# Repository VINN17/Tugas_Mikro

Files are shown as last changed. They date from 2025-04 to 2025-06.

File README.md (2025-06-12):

# 🚧 Building Automation System (BAS) untuk Pompa Air Jalan Tol
### Solusi Banjir dan Kemacetan saat Hujan Berkepanjangan

<div align="center">
  
</div>

https://github.com/user-attachments/assets/4135e06a-734f-496c-8481-714472587500

## 📚 Daftar Isi

1. [📌 Deskripsi Proyek](#-deskripsi-proyek)
2. [🎯 Tujuan Proyek](#-tujuan-proyek)
3. [🛠️ Teknologi dan Komponen](#️-teknologi-dan-komponen)
4. [⚙️ Cara Kerja Sistem](#️-cara-kerja-sistem)
5. [🧩 Diagram Alur Sistem](#-diagram-alur-sistem)
6. [🌟 Keunggulan Proyek](#-keunggulan-proyek)
7. [📈 Potensi Pengembangan](#-potensi-pengembangan)
8. [🤝 Kolaborasi & Dukungan](#-kolaborasi--dukungan)
9. [👥 Struktur Tim](#-struktur-tim)
10. [📩 Hubungi Kami](#-hubungi-kami)

---

## 📌 Deskripsi Proyek

**Building Automation Systems** ini dirancang untuk mengotomatisasi pengoperasian **pompa air pada jalan tol** guna mengatasi genangan atau banjir secara cepat dan efisien.

Dengan memanfaatkan sensor debit dan volume air, sistem ini mampu menghidupkan atau mematikan pompa secara otomatis berdasarkan data real-time, sehingga meningkatkan **keamanan** dan **kenyamanan** pengguna jalan.

> Dikembangkan berbasis **Arduino Uno** dan sistem monitoring berbasis GUI, proyek ini menawarkan solusi otomasi yang **andal**, **efisien**, dan **mudah diimplementasikan**.

---

## 🎯 Tujuan Proyek

* **Efisiensi Operasional Maksimal**
  Sistem mengeliminasi keterlambatan manual dan mengoptimalkan respons terhadap kondisi air.

* **Minimalkan Risiko Human Error**
  Pengambilan keputusan berbasis data sensor menghindari kesalahan dalam penanganan banjir.

* **Solusi Otomasi Biaya Terjangkau**
  Menggunakan komponen yang tersedia di pasaran dengan biaya rendah, ideal untuk skalabilitas.

---

## 🛠️ Teknologi dan Komponen



| Komponen | Spesifikasi |
| --- | --- |
| Mikrokontroler | Arduino Uno |
| Sensor Debit Air | Pressure Sensor |
| Sensor Volume Air  | Ultrasonic / Water Level Sensor |
| Aktuator | Pompa Air + Relay Module |
| Antarmuka Pengguna | GUI berbasis Figma (Start/Stop, Monitoring)  |
| Komunikasi Data | Serial / Wireless (pengembangan selanjutnya) |

---

## ⚙️ Cara Kerja Sistem

1. Sensor membaca **debit** dan **volume air** secara berkala.
2. Data dikirim ke mikrokontroler dan dibandingkan dengan nilai **set point**.
3. **Logika Kendali Otomatis**:

   * Jika data melebihi ambang → **Pompa ON**
   * Jika data aman → **Pompa OFF**
4. Status sistem ditampilkan pada GUI untuk **monitoring real-time**.
5. Operator dapat melakukan **manual override** dari GUI bila dibutuhkan.

---

## 🧩 Diagram Alur Sistem



**Penjelasan Alur:**

* Sistem dimulai melalui tampilan GUI.

* Pengguna memilih mode: **Auto** atau **Manual**.

  * **Auto**: sensor membaca data → kirim ke GUI → kontrol pompa otomatis.
  * **Manual**: pengguna dapat menyalakan/mematikan pompa secara langsung.

* Sistem akan terus berjalan sampai dihentikan manual oleh operator.

---

## 💻 PCB



Diatas  merupakan desain PCB jadi 

---

## 🌟 Keunggulan Proyek

* ✅ **Respon Real-Time** terhadap potensi banjir.
* ✅ **Kontrol Terpusat & Mudah** dari satu GUI.
* ✅ **Terintegrasi dengan IoT/SCADA** untuk masa depan.
* ✅ **Desain Scalable** & mudah diadaptasi ke area baru.
* ✅ **Ramah Anggaran** untuk implementasi massal.

---

## 📈 Potensi Pengembangan

* 🌐 **Integrasi ke IoT Cloud**: akses global & notifikasi otomatis.
* 🔔 **Peringatan SMS/WhatsApp** saat kondisi kritis.
* 🧠 **Prediksi Banjir Berbasis AI**: analisis historis dengan Machine Learning.
* 🏙️ **Kompatibel dengan Smart City Infrastructure**.

---

## 🤝 Kolaborasi & Dukungan

Kami membuka peluang kerja sama dengan:

* 🔧 **Investor teknologi** yang tertarik pada otomasi infrastruktur.
* 🛣️ **Pemerintah / Operator Jalan Tol** untuk penerapan langsung.
* 🧪 **Startup atau perusahaan R\&D** yang ingin mengembangkan solusi pintar dan berdampak.

> 🎯 Kami siap melakukan presentasi, demo proyek, dan diskusi lanjutan bersama mitra strategis.

---

## 👥 Struktur Tim



| NRP | Nama | Peran Utama |
| --- | --- | --- |
| 2123600010 | Imam | Project Manager |
| 2123600014 | Ferri | Desain PCB |
| 2123600004 | Robith  | Spesialis Hardware |
| 2123600030 | Zach | Pengembang Software |
| 2123600023 | Choirul | Desainer 3D |
| 2123600019 | Andira  | Non-Teknis & Dokumentasi |

---

## 📩 Hubungi Kami

📧 Untuk kerja sama, pertanyaan, atau demo proyek:

**Email Project Manager**: [immarfn17@gmail.com](mailto:immarfn17@gmail.com)

https://github.com/user-attachments/assets/88c9bd39-f75d-4216-a4de-ee6d6c01959d
> 🚀 Mari bersama kita ciptakan masa depan infrastruktur jalan tol yang lebih **cerdas**, **aman**, dan **berkelanjutan**.

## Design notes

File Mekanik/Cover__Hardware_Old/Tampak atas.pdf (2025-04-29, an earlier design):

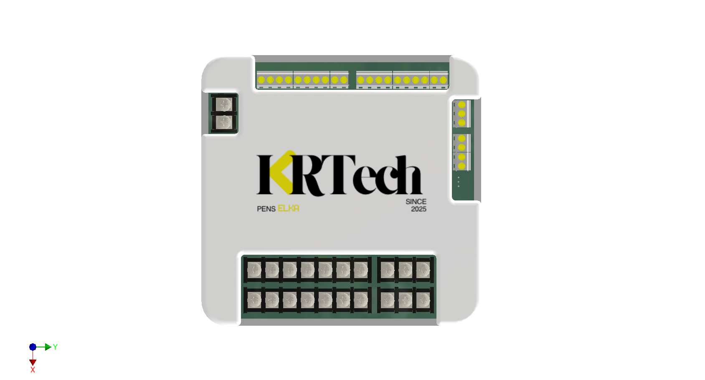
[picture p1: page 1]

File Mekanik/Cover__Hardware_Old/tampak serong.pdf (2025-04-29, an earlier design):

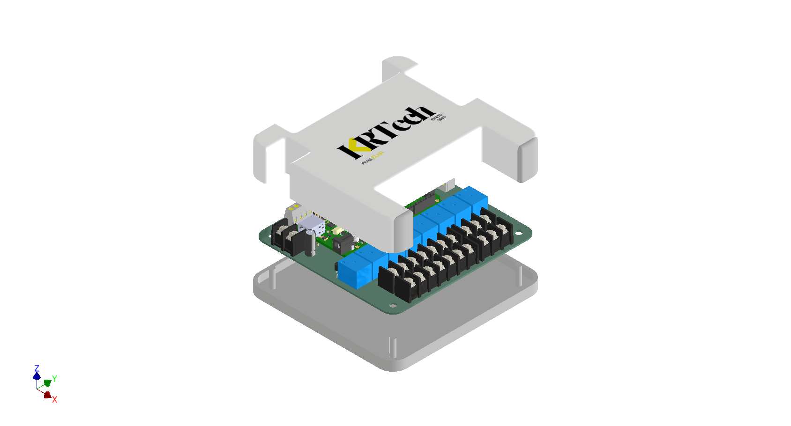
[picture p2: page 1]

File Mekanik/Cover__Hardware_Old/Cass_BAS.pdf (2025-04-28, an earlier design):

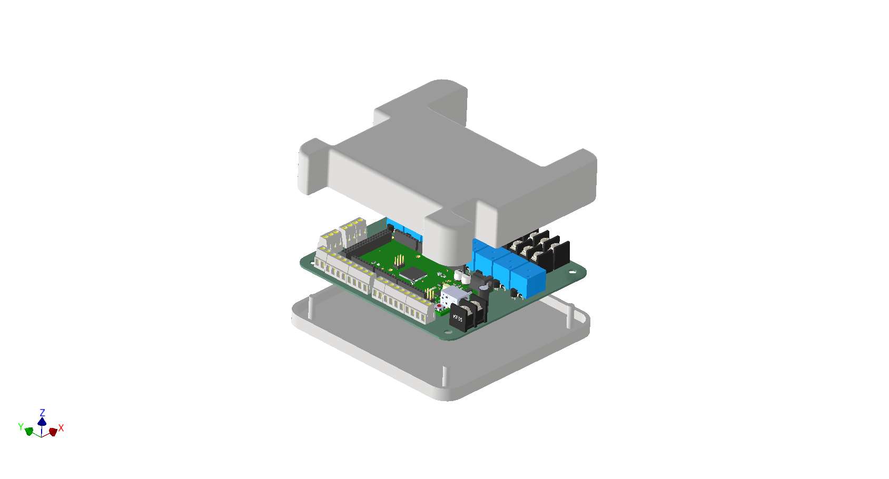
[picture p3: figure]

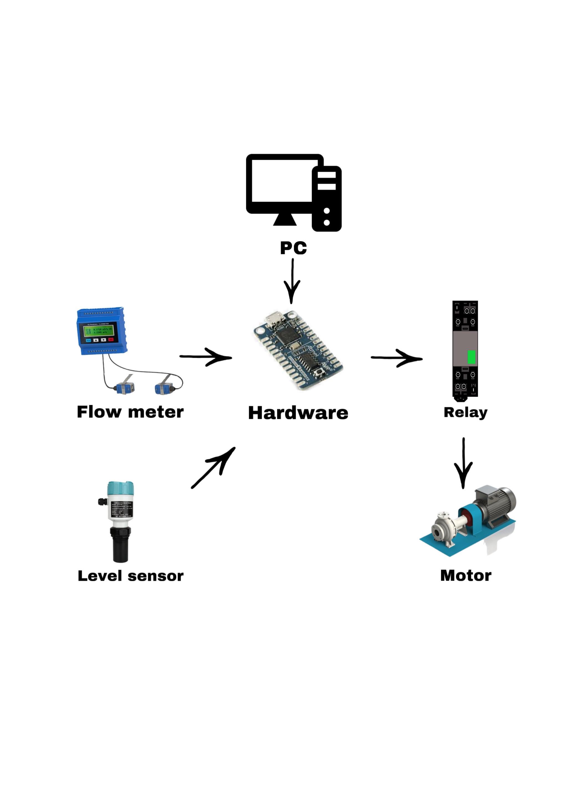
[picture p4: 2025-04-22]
Arsitekture Design.jpeg

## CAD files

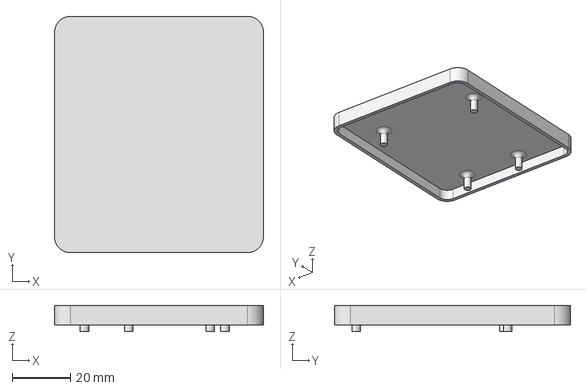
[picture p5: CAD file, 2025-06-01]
Mekanik/Cover_Hardware_New/part1.stp
71.8 x 81.2 x 9.00 mm

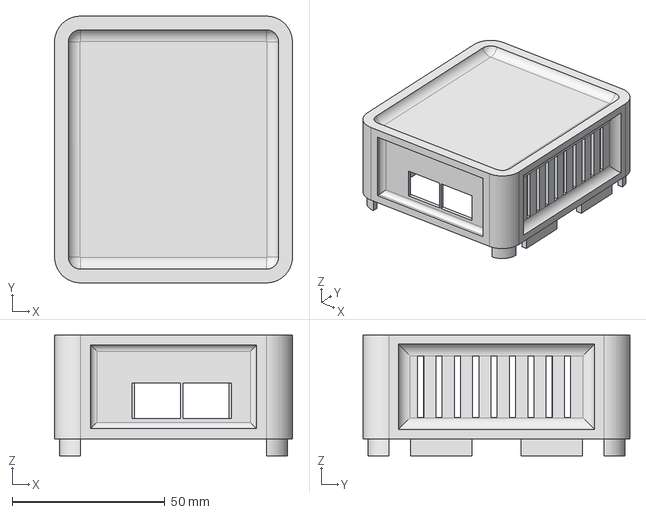
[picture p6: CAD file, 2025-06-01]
Mekanik/Cover_Hardware_New/pirnt3d/Part3.stp
77.8 x 87.2 x 39.5 mm

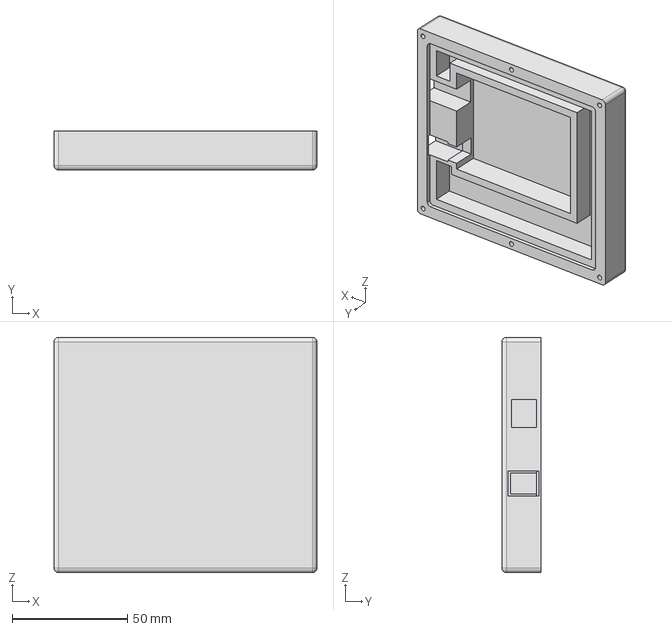
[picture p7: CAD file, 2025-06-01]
Mekanik/Cover_Hardware_New/pirnt3d/12.stp
114.0 x 17.0 x 102.0 mm

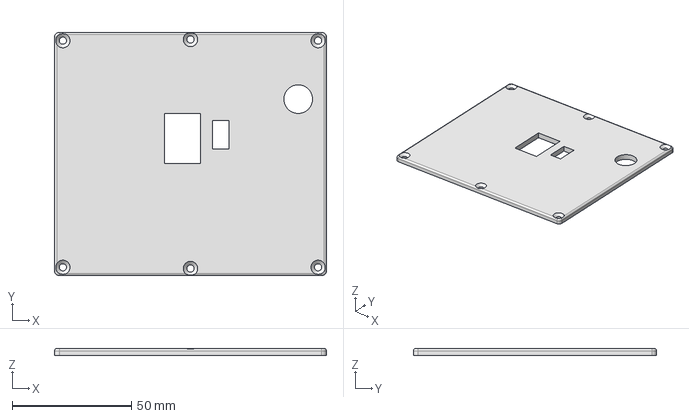
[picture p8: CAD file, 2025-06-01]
Mekanik/Cover_Hardware_New/pirnt3d/tutup cover12.stp
114.0 x 102.0 x 3.00 mm

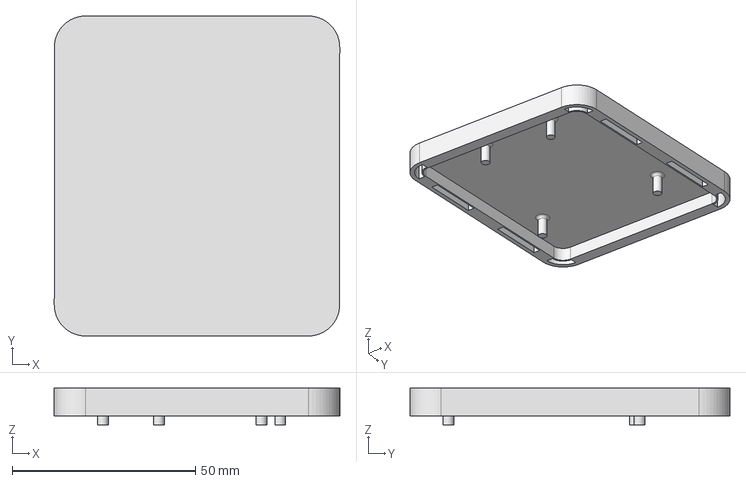
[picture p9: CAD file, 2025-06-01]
Mekanik/Cover_Hardware_New/pirnt3d/part1.stp
77.8 x 87.2 x 10.0 mm

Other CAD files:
Hardware/BAS_Hardware/BAS_Hardware/BAS_Hardware/05KJ_Mini_PCB_Regulator.ipt
Hardware/BAS_Hardware/BAS_Hardware/BAS_Hardware/05KJ_Mini_PCB_Regulator_With_Pin_Assem_.iam
Hardware/BAS_Hardware/BAS_Hardware/BAS_Hardware/1_Male_Pin_2.54_mm.ipt
Hardware/BAS_Hardware/BAS_Hardware/BAS_Hardware/2er Terminal Block.iam
Hardware/BAS_Hardware/BAS_Hardware/BAS_Hardware/3er Terminal Block.iam
Hardware/BAS_Hardware/BAS_Hardware/BAS_Hardware/4er Terminal Block.iam
Hardware/BAS_Hardware/BAS_Hardware/BAS_Hardware/BAS_Hardware 1.12.1.ipt
Hardware/BAS_Hardware/BAS_Hardware/BAS_Hardware/BAS_Hardware 1.40.1.ipt
Hardware/BAS_Hardware/BAS_Hardware/BAS_Hardware/BAS_Hardware 1.7.1.ipt
Hardware/BAS_Hardware/BAS_Hardware/BAS_Hardware/BAS_Hardware_PCB.ipt
Hardware/BAS_Hardware/BAS_Hardware/BAS_Hardware/COMPOUND.ipt
Hardware/BAS_Hardware/BAS_Hardware/BAS_Hardware/D_DO-41_SOD81_P10.16mm_Horizontal.ipt
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

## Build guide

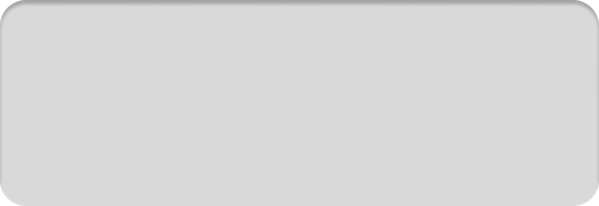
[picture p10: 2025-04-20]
program/Program_Mikro/build/assets/frame0/entry_3.png

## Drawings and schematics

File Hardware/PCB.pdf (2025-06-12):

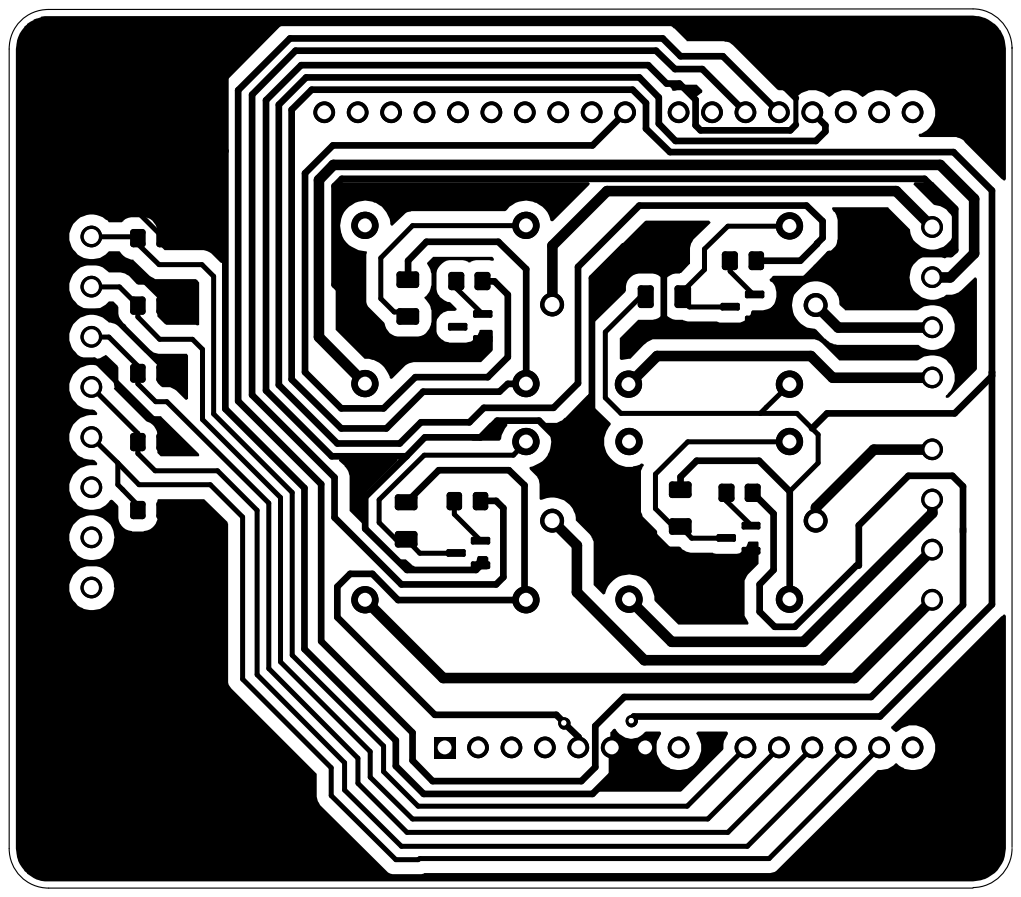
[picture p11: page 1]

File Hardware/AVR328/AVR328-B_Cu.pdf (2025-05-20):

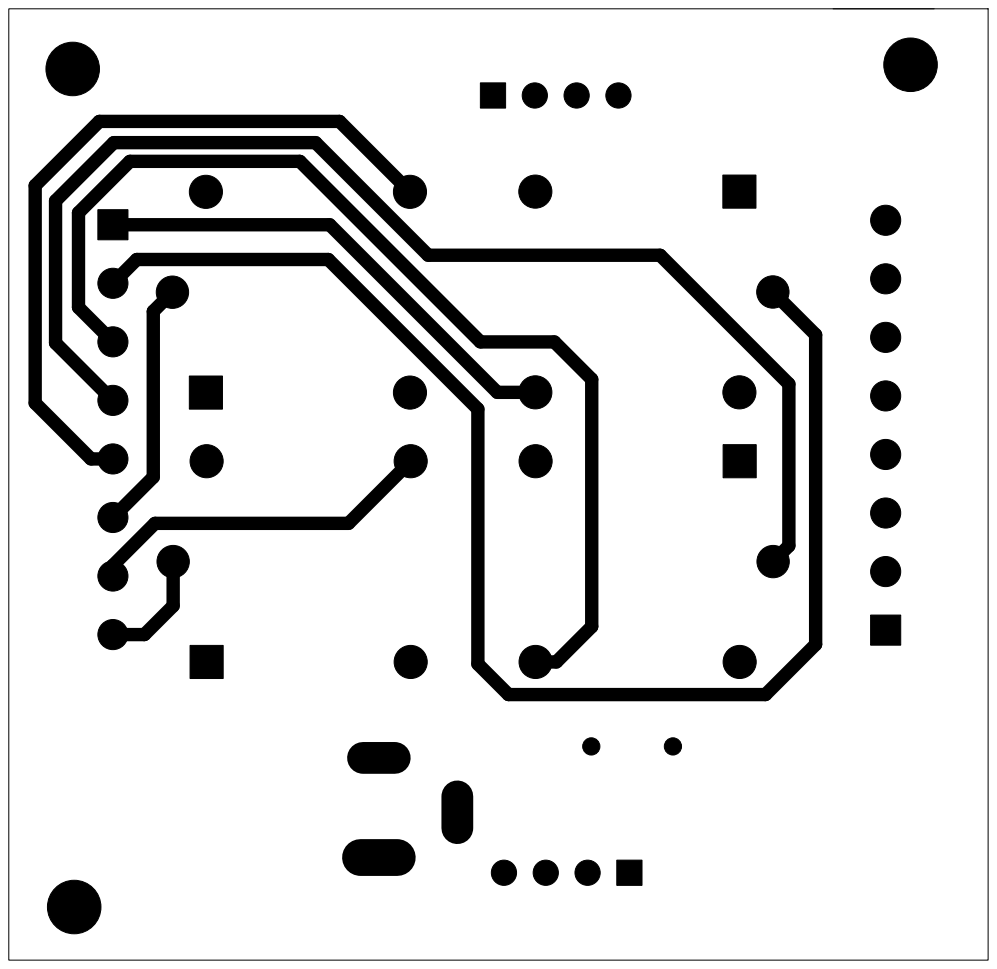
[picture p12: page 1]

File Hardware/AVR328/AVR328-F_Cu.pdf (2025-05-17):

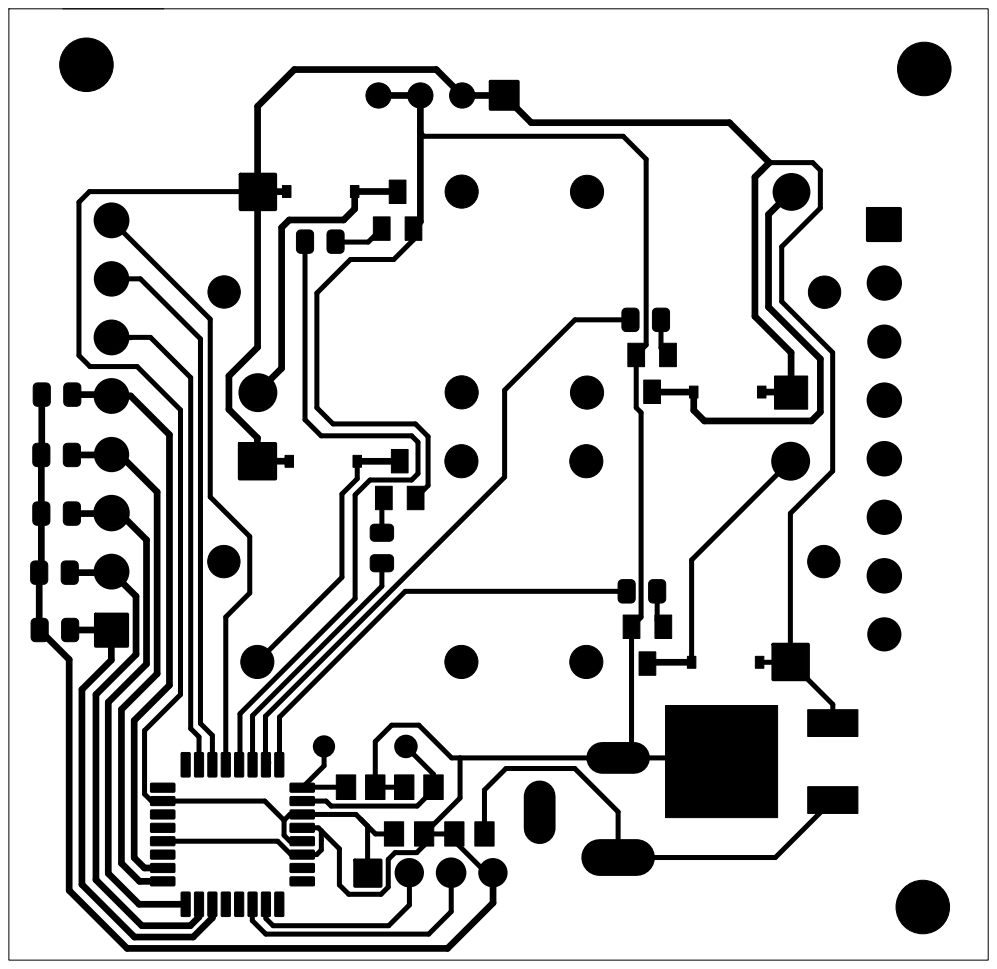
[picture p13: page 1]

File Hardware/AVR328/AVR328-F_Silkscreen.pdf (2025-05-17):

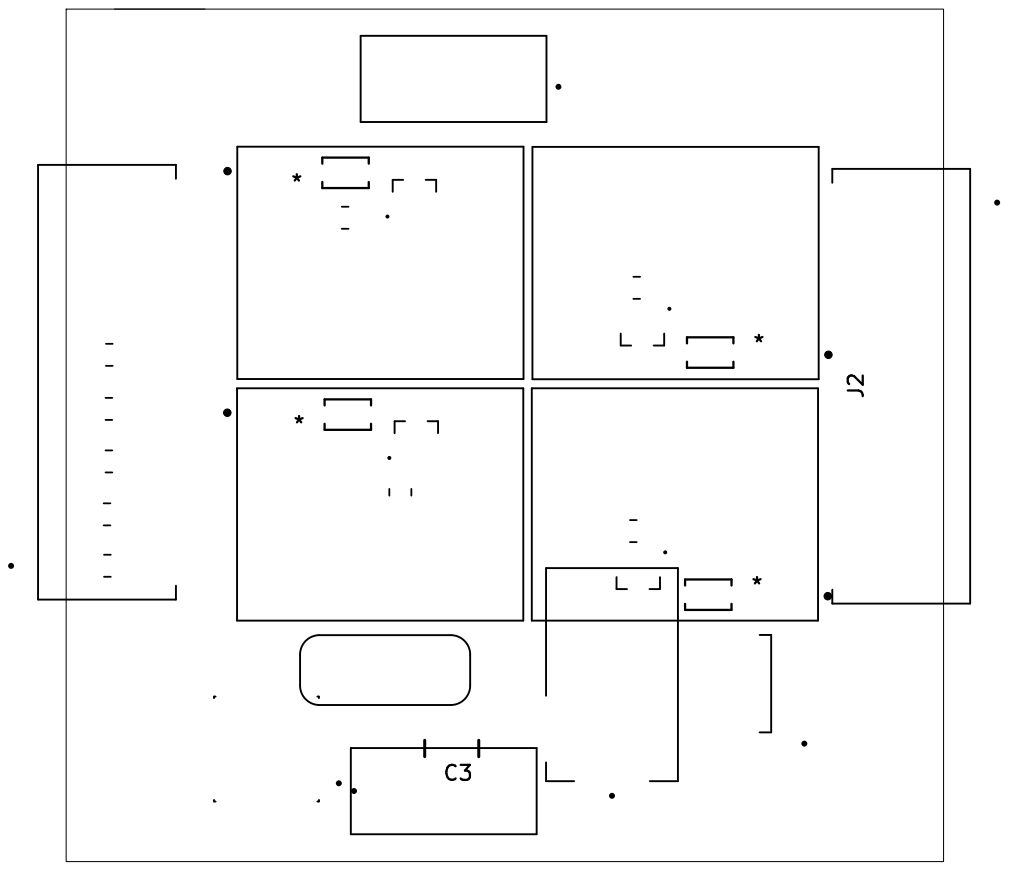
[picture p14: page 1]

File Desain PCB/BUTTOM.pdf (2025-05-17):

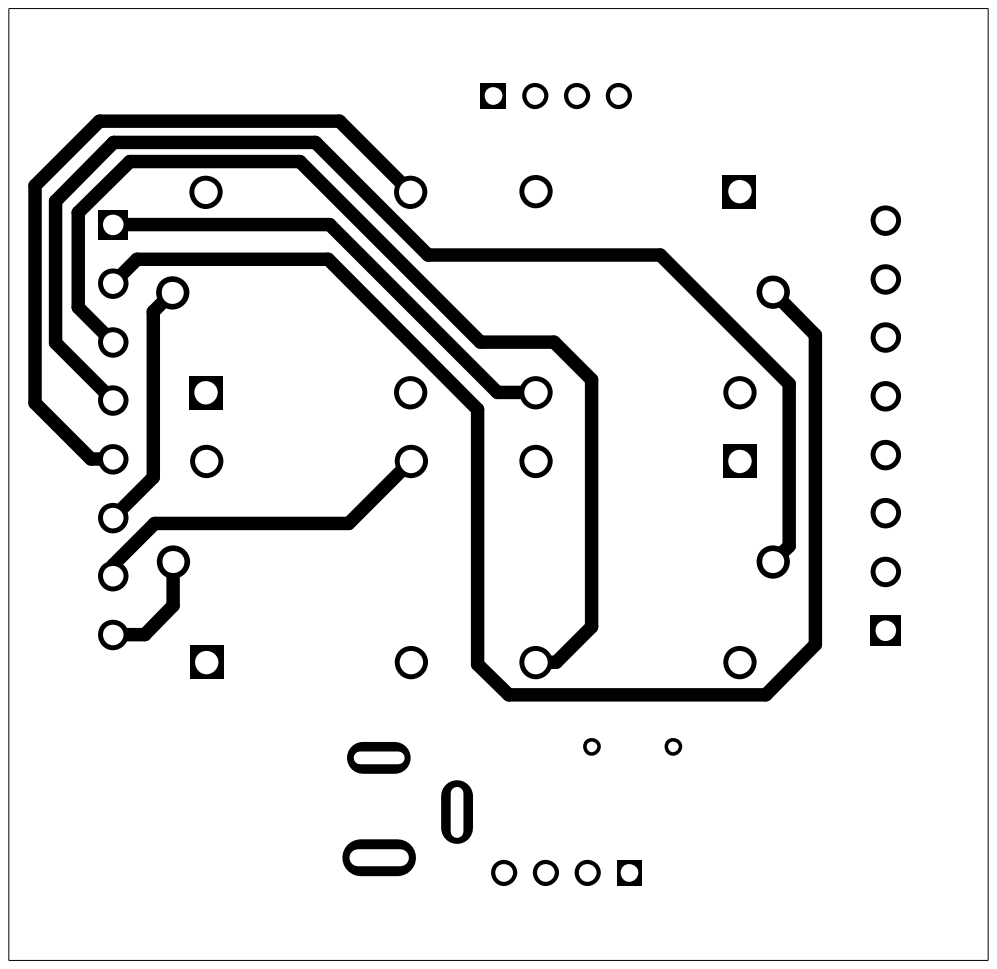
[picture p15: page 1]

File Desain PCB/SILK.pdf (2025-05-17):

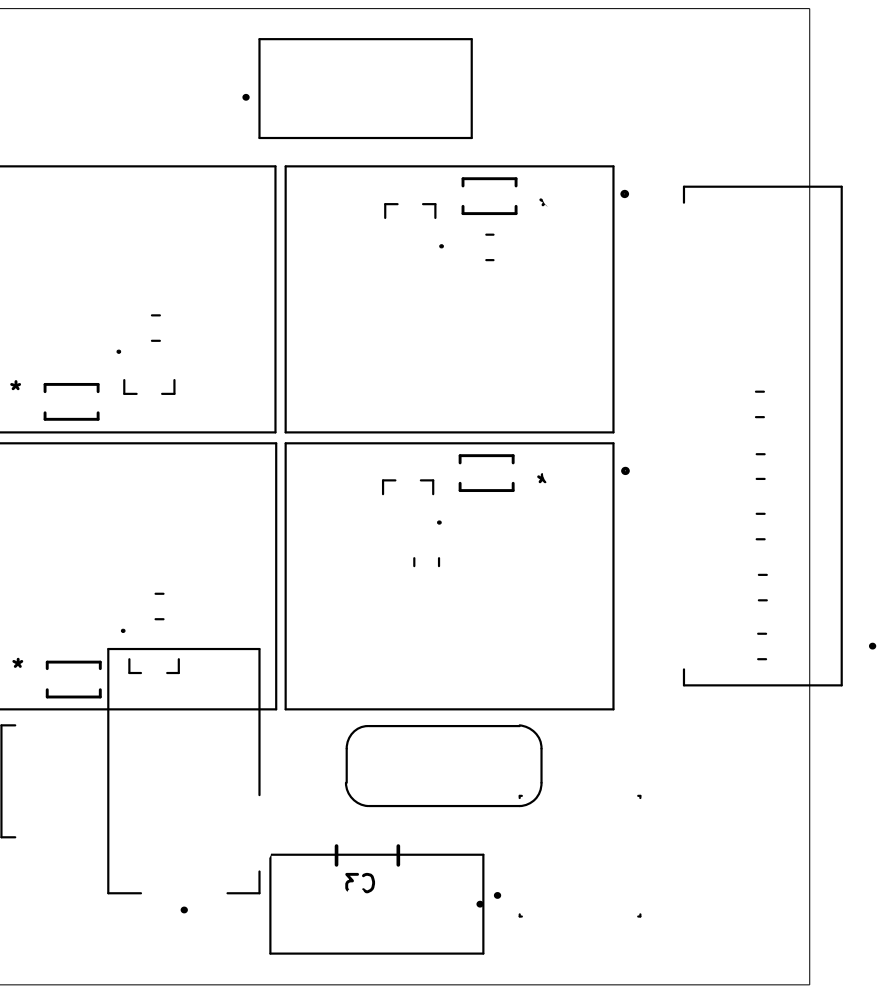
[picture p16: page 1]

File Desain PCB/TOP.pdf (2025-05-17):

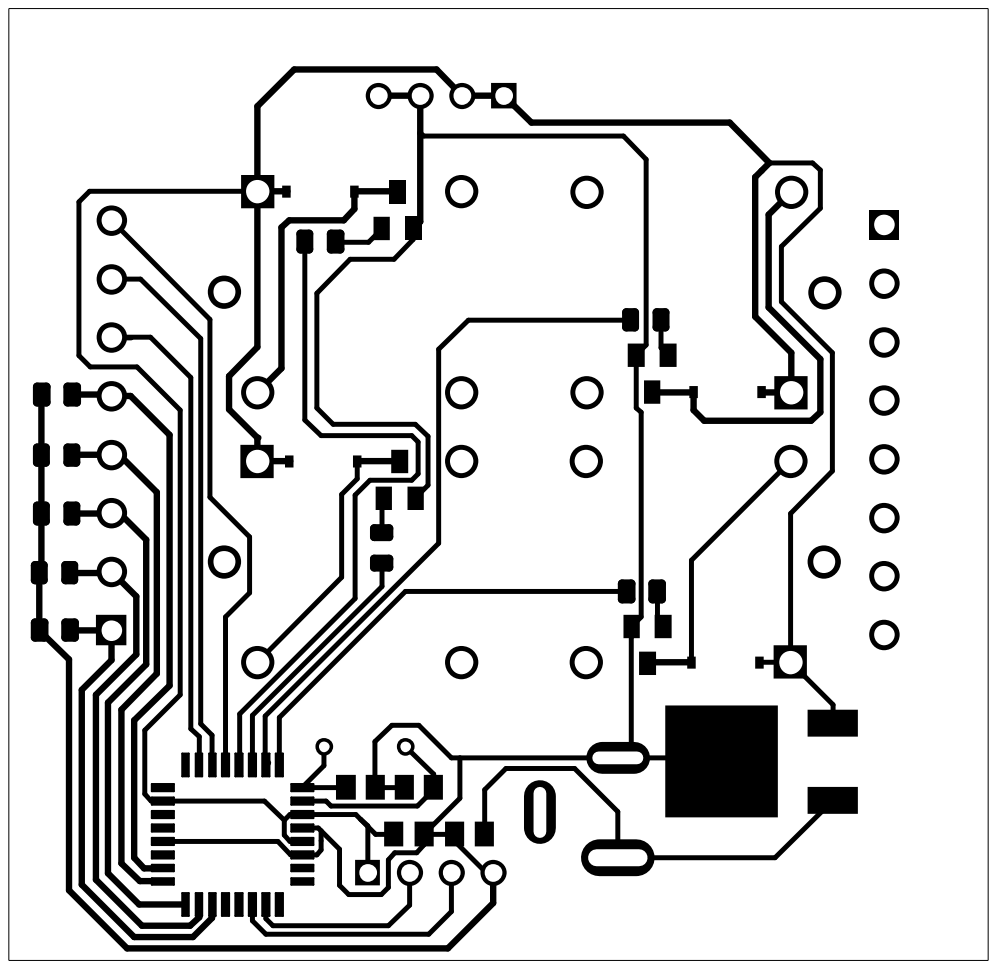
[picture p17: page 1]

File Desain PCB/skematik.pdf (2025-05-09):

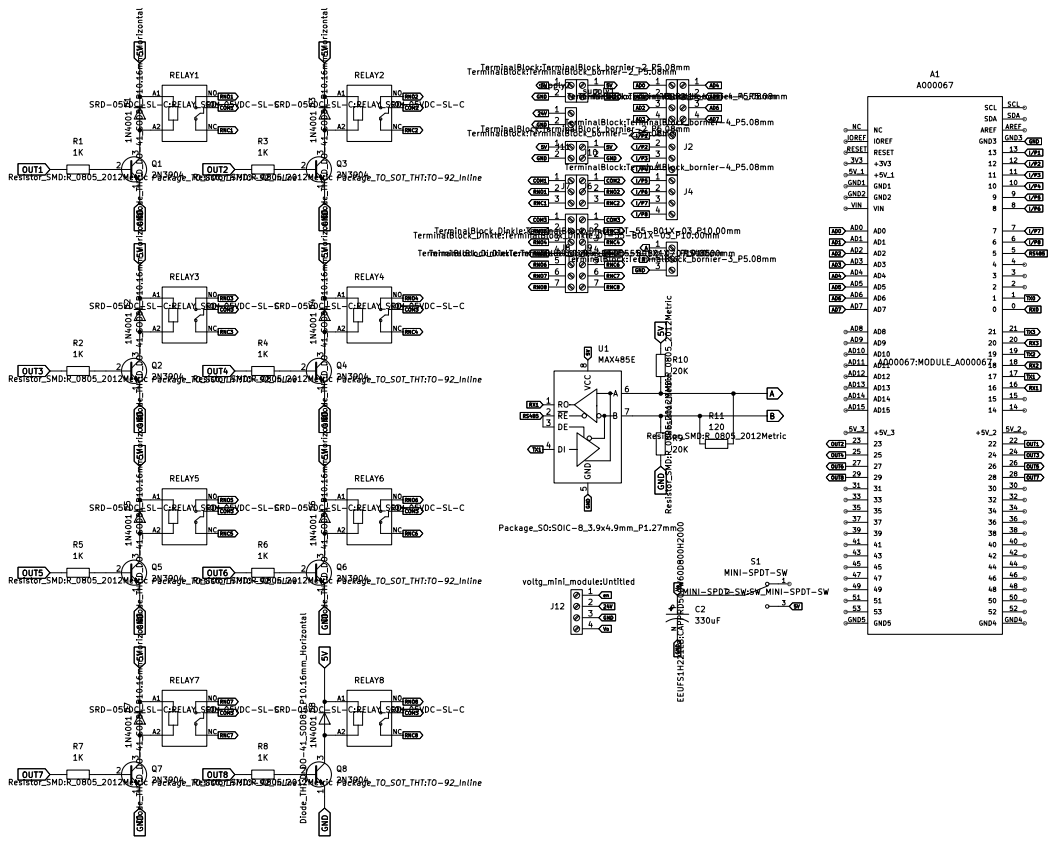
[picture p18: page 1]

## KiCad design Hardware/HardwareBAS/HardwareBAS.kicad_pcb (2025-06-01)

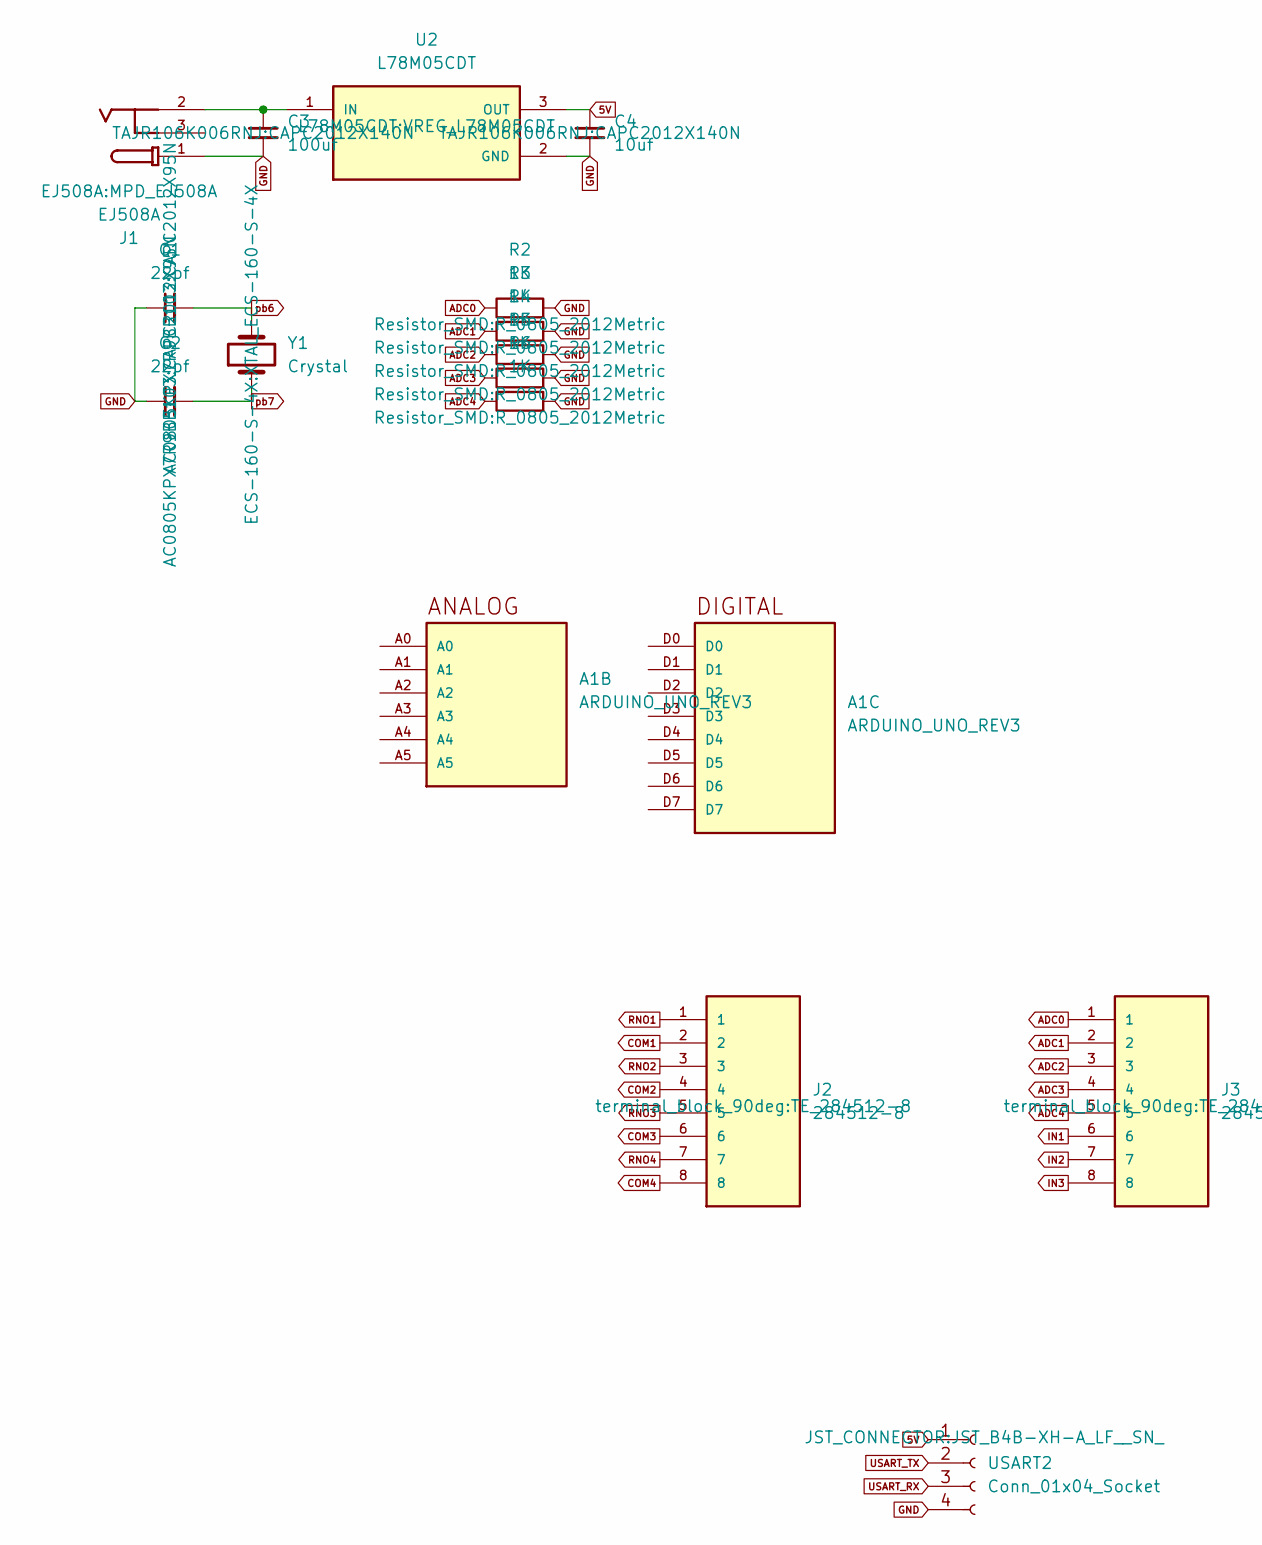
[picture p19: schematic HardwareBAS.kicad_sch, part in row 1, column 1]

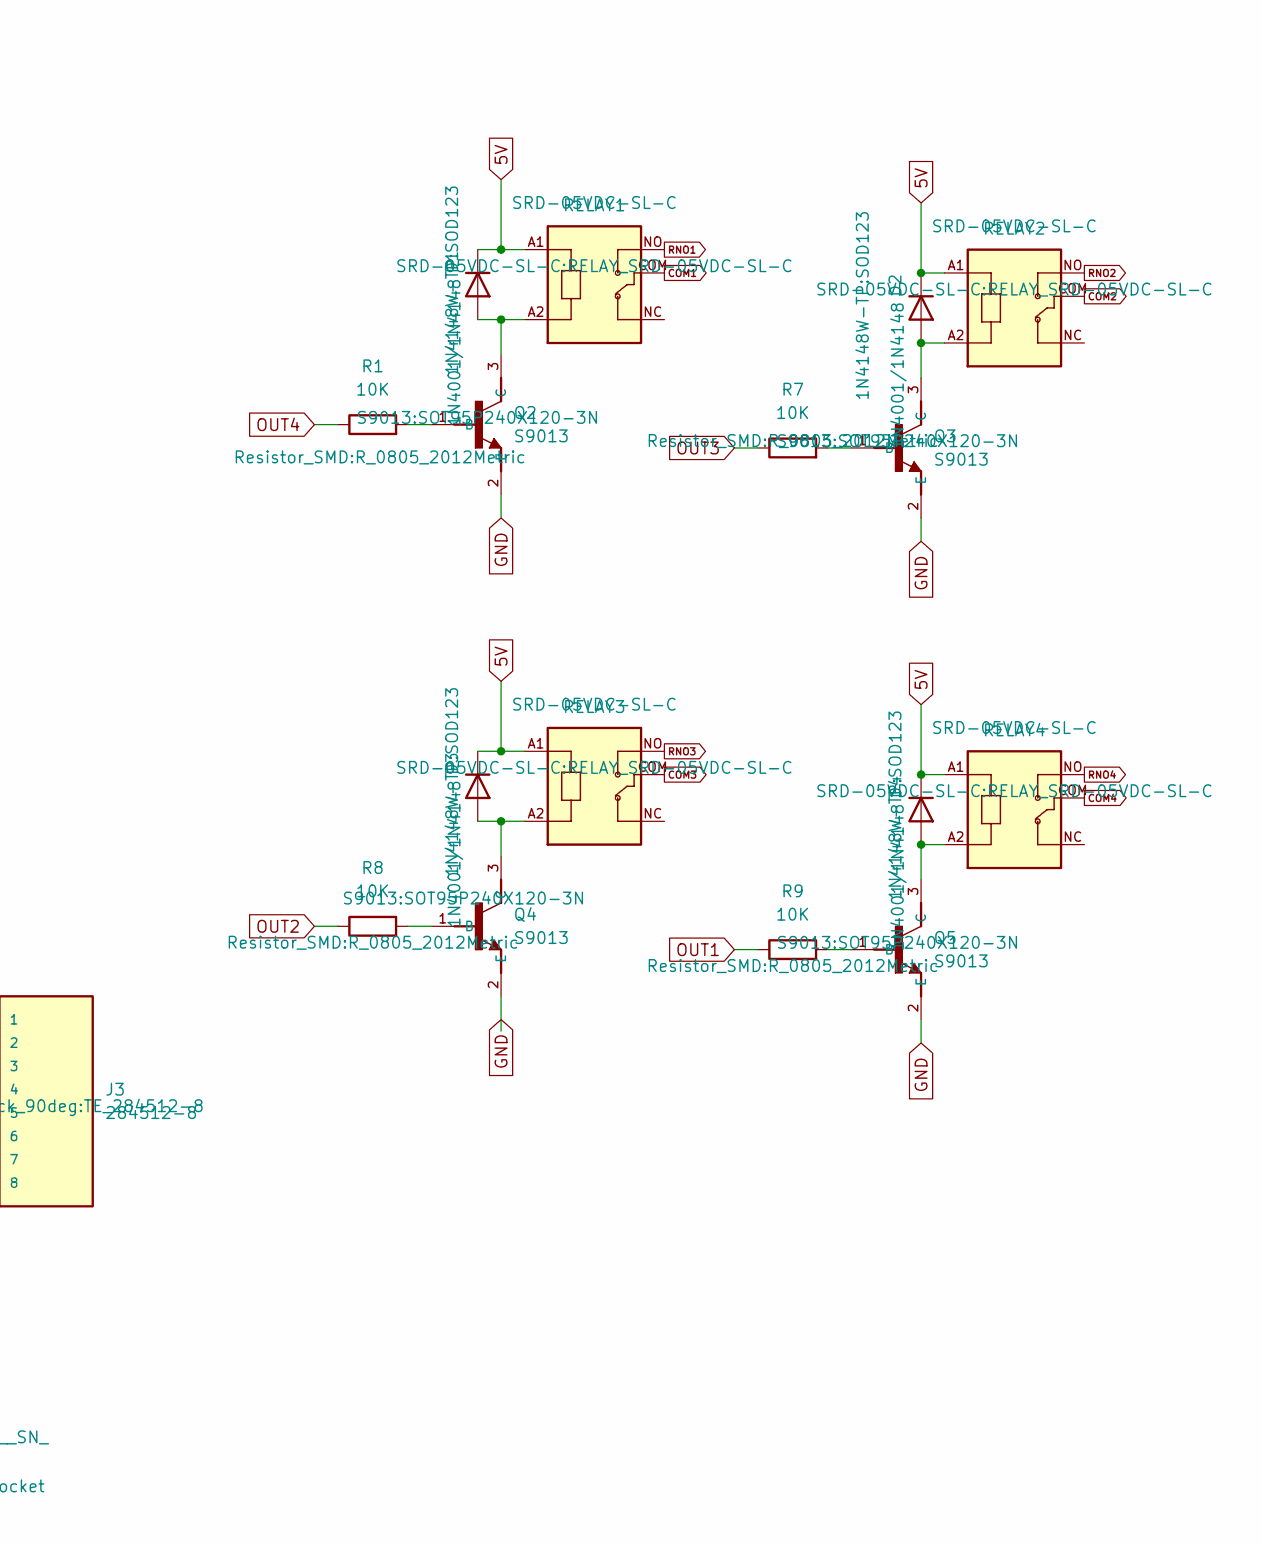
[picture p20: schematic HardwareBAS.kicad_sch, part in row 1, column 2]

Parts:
A1: ARDUINO_UNO_REV3; ARDUINO_ARDUINO_UNO_REV3; PARTREV N/A
C1, C2: 22pf; CAPC2012X95N
C3: 100uf; CAPC2012X140N
C4: 10uf; CAPC2012X140N
D1, D2, D3, D4: 1N4001/1N4148; SOD123
J1: EJ508A; MPD_EJ508A; PARTREV J
J2, J3: 284512-8; TE_284512-8; PARTREV R
Q2, Q3, Q4, Q5: S9013; SOT95P240X120-3N
R1, R7, R8, R9: 10K; R_0805_2012Metric
R2, R3, R4, R5, R6: 1K; R_0805_2012Metric
RELAY1, RELAY2, RELAY3, RELAY4: SRD-05VDC-SL-C; RELAY_SRD-05VDC-SL-C
U2: L78M05CDT; VREG_L78M05CDT; PARTREV 24
USART2: Conn_01x04_Socket; JST_B4B-XH-A_LF__SN_
Y1: Crystal; XTAL_ECS-160-S-4X

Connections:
5V: C4.1, D1.1 (K), D2.1 (K), D3.1 (K), D4.1 (K), RELAY1.A1, RELAY2.A1, RELAY3.A1, RELAY4.A1, U2.3 (OUT), USART2.1
ADC0: J3.1, R2.1
ADC1: J3.2, R3.1
ADC2: J3.3, R4.1
ADC3: J3.4, R5.1
ADC4: J3.5, R6.1
COM1: J2.2, RELAY1.COM
COM2: J2.4, RELAY2.COM
COM3: J2.6, RELAY3.COM
COM4: J2.8, RELAY4.COM
GND: C1.1, C2.1, C3.2, C4.2, J1.1, Q2.2 (E), Q3.2 (E), Q4.2 (E), Q5.2 (E), R2.2, R3.2, R4.2, R5.2, R6.2, U2.2 (GND), USART2.4
IN1: J3.6
IN2: J3.7
IN3: J3.8
unnamed: D1.2 (A), Q2.3 (C), RELAY1.A2
unnamed: D2.2 (A), Q3.3 (C), RELAY2.A2
unnamed: D3.2 (A), Q4.3 (C), RELAY3.A2
unnamed: D4.2 (A), Q5.3 (C), RELAY4.A2
unnamed: Q2.1 (B), R1.2
unnamed: Q3.1 (B), R7.2
unnamed: Q4.1 (B), R8.2
unnamed: Q5.1 (B), R9.2
unnamed: C3.1, J1.2, U2.1 (IN)
OUT1: R9.1
OUT2: R8.1
OUT3: R7.1
OUT4: R1.1
RNO1: J2.1, RELAY1.NO
RNO2: J2.3, RELAY2.NO
RNO3: J2.5, RELAY3.NO
RNO4: J2.7, RELAY4.NO
USART_RX: USART2.3
USART_TX: USART2.2
pb6: C1.2, Y1.2
pb7: C2.2, Y1.1

Board: 2 copper layers, 32 parts (0 on the bottom side), 26 nets, no tracks yet.

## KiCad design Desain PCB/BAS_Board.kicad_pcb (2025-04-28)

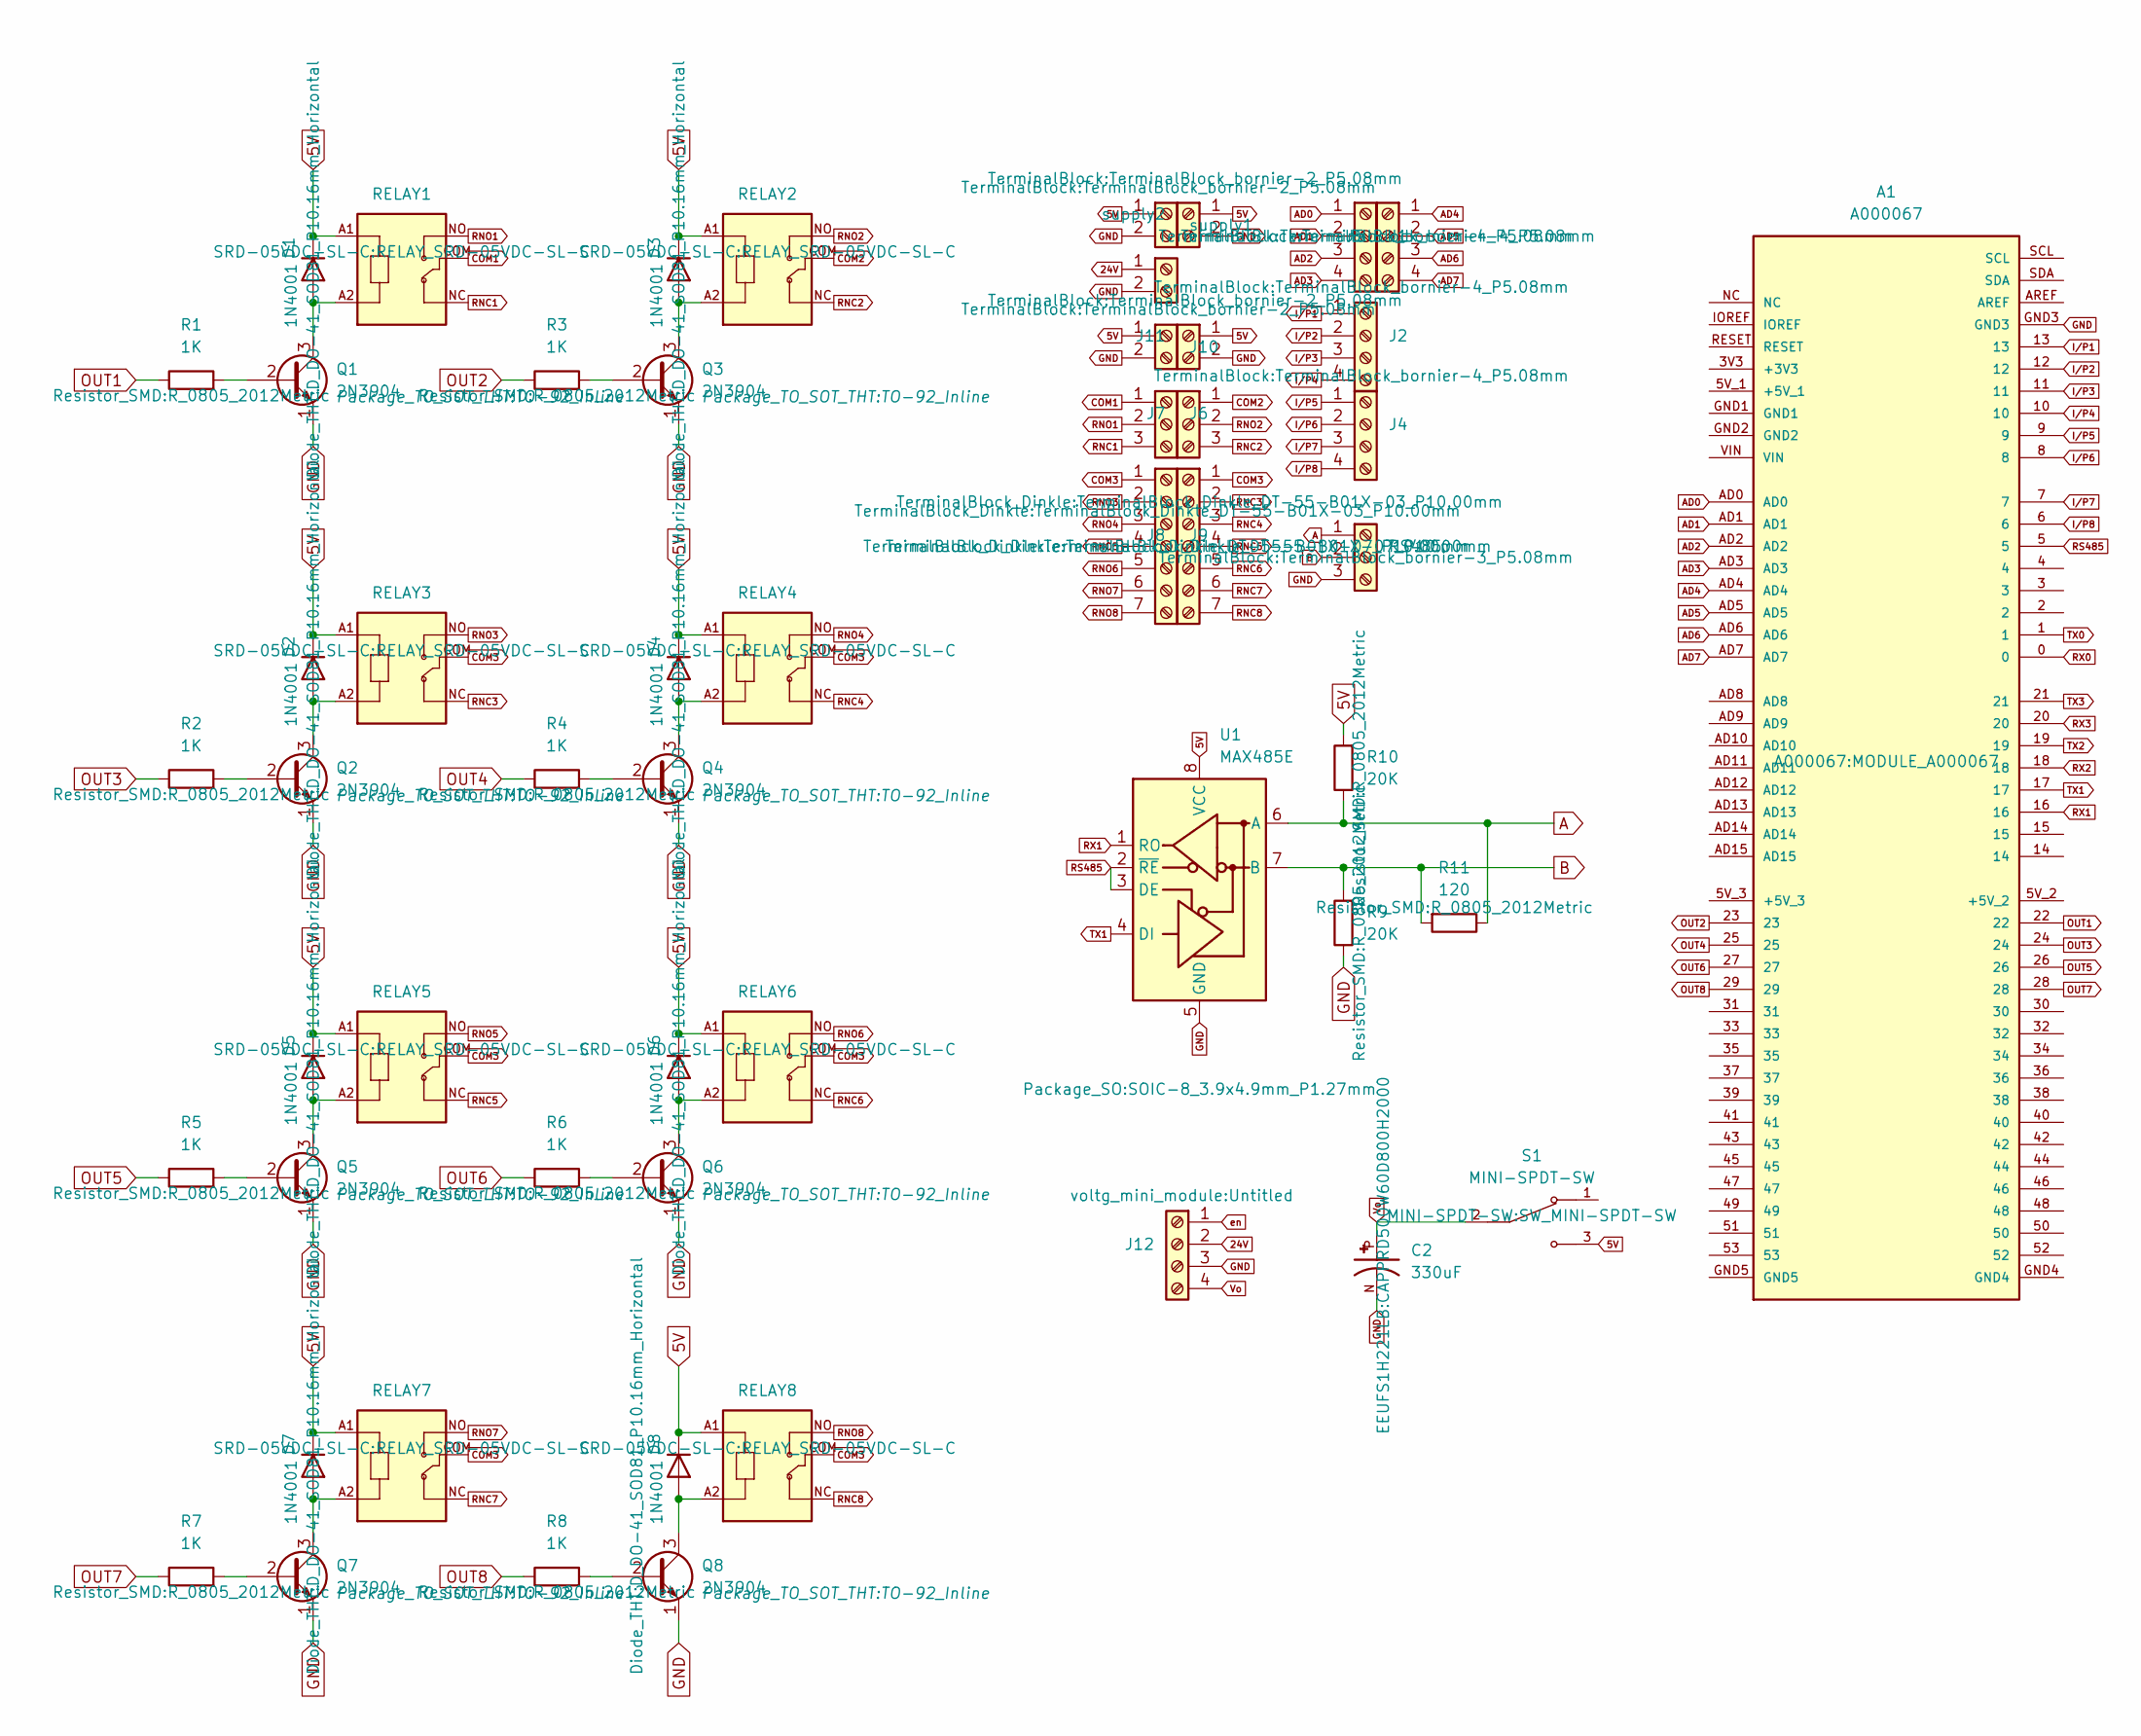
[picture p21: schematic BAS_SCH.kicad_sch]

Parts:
A1: A000067; MODULE_A000067; PARTREV 3; DigiKey_Part_Number 1050-1018-ND
C2: 330uF; CAPPRD500W60D800H2000; PARTREV 28-FEB-20; DigiKey_Part_Number P122329CT-ND
D1, D2, D3, D4, D5, D6, D7, D8: 1N4001; D_DO-41_SOD81_P10.16mm_Horizontal
J1, J2, J4, J5: Screw_Terminal_01x04; TerminalBlock_bornier-4_P5.08mm
J6, J7: Screw_Terminal_01x03; TerminalBlock_Dinkle_DT-55-B01X-03_P10.00mm
J8, J9: Screw_Terminal_01x07; TerminalBlock_Dinkle_DT-55-B01X-07_P10.00mm
J10, J11: Screw_Terminal_01x02; TerminalBlock_bornier-2_P5.08mm
J12: Screw_Terminal_01x04; Untitled
Power1: Screw_Terminal_01x02; TerminalBlock_Dinkle_DT-55-B01X-02_P10.00mm
Q1, Q2, Q3, Q4, Q5, Q6, Q7, Q8: 2N3904; TO-92_Inline
R1, R2, R3, R4, R5, R6, R7, R8: 1K; R_0805_2012Metric
R9, R10: 20K; R_0805_2012Metric
R11: 120; R_0805_2012Metric
RELAY1, RELAY2, RELAY3, RELAY4, RELAY5, RELAY6, RELAY7, RELAY8: SRD-05VDC-SL-C; RELAY_SRD-05VDC-SL-C
RS485: Screw_Terminal_01x03; TerminalBlock_bornier-3_P5.08mm
S1: MINI-SPDT-SW; SW_MINI-SPDT-SW; PARTREV C
U1: MAX485E; SOIC-8_3.9x4.9mm_P1.27mm
supply1, supply2: Screw_Terminal_01x02; TerminalBlock_bornier-2_P5.08mm

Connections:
5V: D1.1 (K), D2.1 (K), D3.1 (K), D4.1 (K), D5.1 (K), D6.1 (K), D7.1 (K), D8.1 (K), J10.1, J11.1, R10.2, RELAY1.A1, RELAY2.A1, RELAY3.A1, RELAY4.A1, RELAY5.A1, RELAY6.A1, RELAY7.A1, RELAY8.A1, S1.3, U1.8 (VCC), supply1.1, supply2.1
24V: J12.2, Power1.1
A: R10.1, R11.1, RS485.1, U1.6 (A)
AD0: A1.AD0, J1.1
AD1: A1.AD1, J1.2
AD2: A1.AD2, J1.3
AD3: A1.AD3, J1.4
AD4: A1.AD4, J5.1
AD5: A1.AD5, J5.2
AD6: A1.AD6, J5.3
AD7: A1.AD7, J5.4
B: R9.2, R11.2, RS485.2, U1.7 (B)
COM1: J6.1, RELAY1.COM
COM2: J7.1, RELAY2.COM
COM3: J8.1, J9.1, RELAY3.COM, RELAY4.COM, RELAY5.COM, RELAY6.COM, RELAY7.COM, RELAY8.COM
GND: A1.GND3, C2.N, J10.2, J11.2, J12.3, Power1.2, Q1.1 (E), Q2.1 (E), Q3.1 (E), Q4.1 (E), Q5.1 (E), Q6.1 (E), Q7.1 (E), Q8.1 (E), R9.1, RS485.3, U1.5 (GND), supply1.2, supply2.2
I/P1: A1.13, J2.1
I/P2: A1.12, J2.2
I/P3: A1.11, J2.3
I/P4: A1.10, J2.4
I/P5: A1.9, J4.1
I/P6: A1.8, J4.2
I/P7: A1.7, J4.3
I/P8: A1.6, J4.4
unnamed: D1.2 (A), Q1.3 (C), RELAY1.A2
unnamed: D2.2 (A), Q2.3 (C), RELAY3.A2
unnamed: D3.2 (A), Q3.3 (C), RELAY2.A2
unnamed: D4.2 (A), Q4.3 (C), RELAY4.A2
unnamed: D5.2 (A), Q5.3 (C), RELAY5.A2
unnamed: D6.2 (A), Q6.3 (C), RELAY6.A2
unnamed: D7.2 (A), Q7.3 (C), RELAY7.A2
unnamed: D8.2 (A), Q8.3 (C), RELAY8.A2
unnamed: Q1.2 (B), R1.2
unnamed: Q2.2 (B), R2.2
unnamed: Q3.2 (B), R3.2
unnamed: Q4.2 (B), R4.2
unnamed: Q5.2 (B), R5.2
unnamed: Q6.2 (B), R6.2
unnamed: Q7.2 (B), R7.2
unnamed: Q8.2 (B), R8.2
OUT1: A1.22, R1.1
OUT2: A1.23, R3.1
OUT3: A1.24, R2.1
OUT4: A1.25, R4.1
OUT5: A1.26, R5.1
OUT6: A1.27, R6.1
OUT7: A1.28, R7.1
OUT8: A1.29, R8.1
RNC1: J6.3, RELAY1.NC
RNC2: J7.3, RELAY2.NC
RNC3: J8.2, RELAY3.NC
RNC4: J8.3, RELAY4.NC
RNC5: J8.4, RELAY5.NC
RNC6: J8.5, RELAY6.NC
RNC7: J8.6, RELAY7.NC
RNC8: J8.7, RELAY8.NC
RNO1: J6.2, RELAY1.NO
RNO2: J7.2, RELAY2.NO
RNO3: J9.2, RELAY3.NO
RNO4: J9.3, RELAY4.NO
RNO5: J9.4, RELAY5.NO
RNO6: J9.5, RELAY6.NO
RNO7: J9.6, RELAY7.NO
RNO8: J9.7, RELAY8.NO
RS485: A1.5, U1.2 (~RE), U1.3 (DE)
RX0: A1.0
RX1: A1.16, U1.1 (RO)
RX2: A1.18
RX3: A1.20
TX0: A1.1
TX1: A1.17, U1.4 (DI)
TX2: A1.19
TX3: A1.21
Vo: C2.P, J12.4, S1.2
en: J12.1

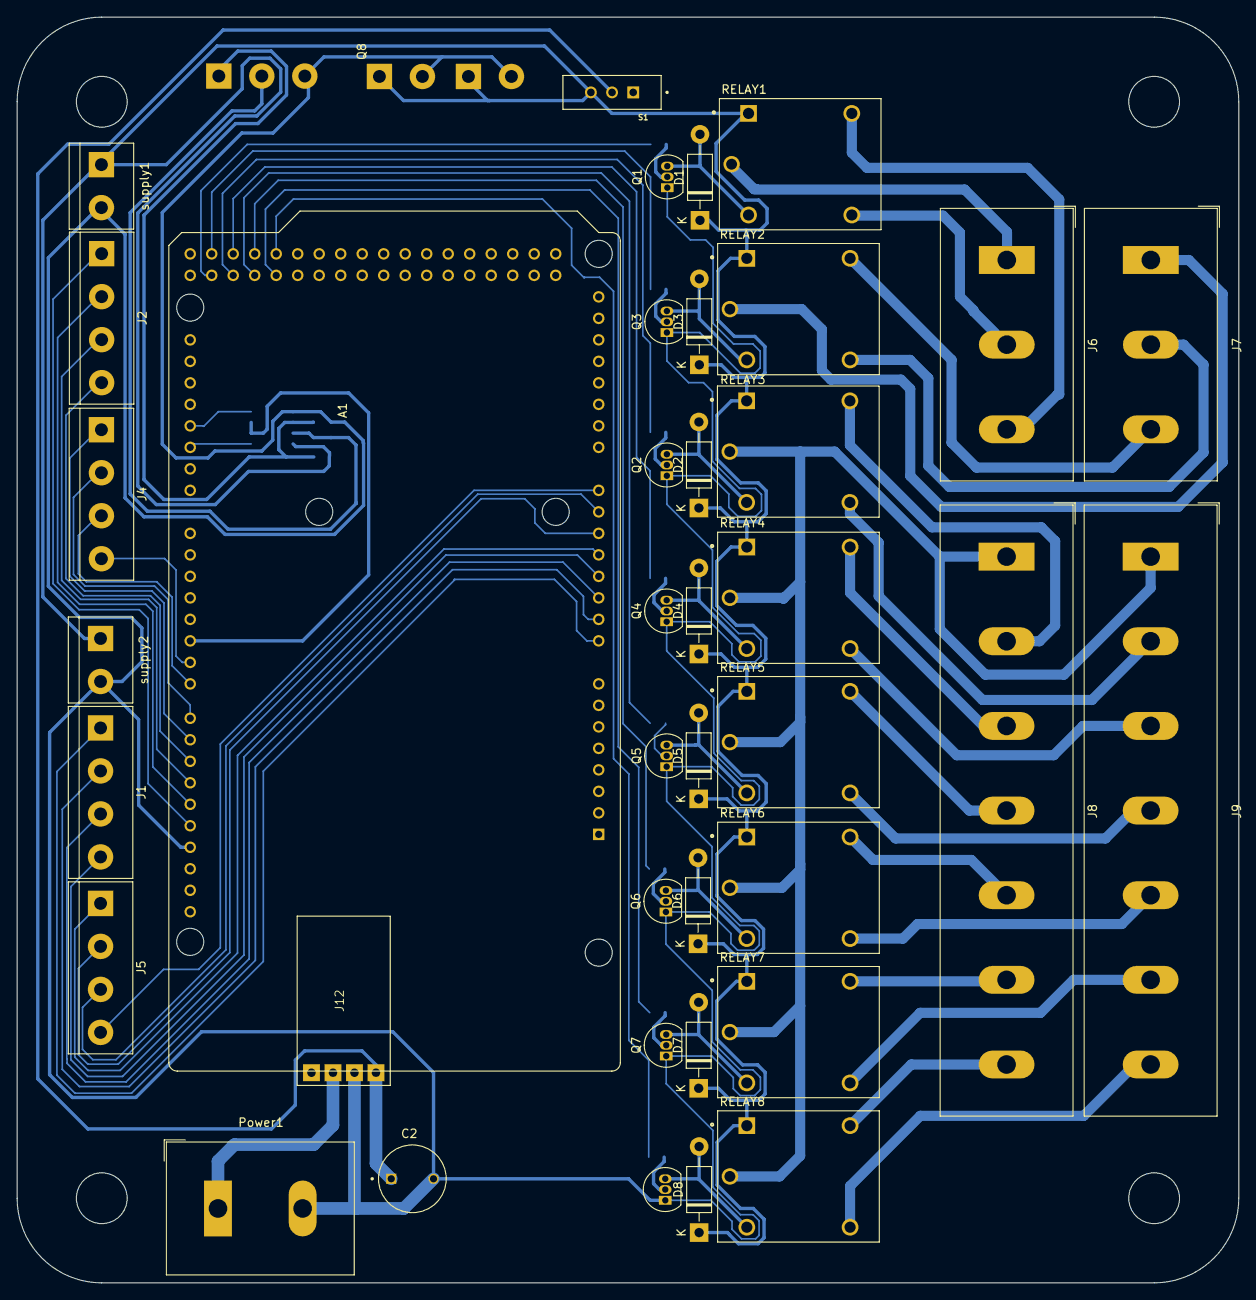
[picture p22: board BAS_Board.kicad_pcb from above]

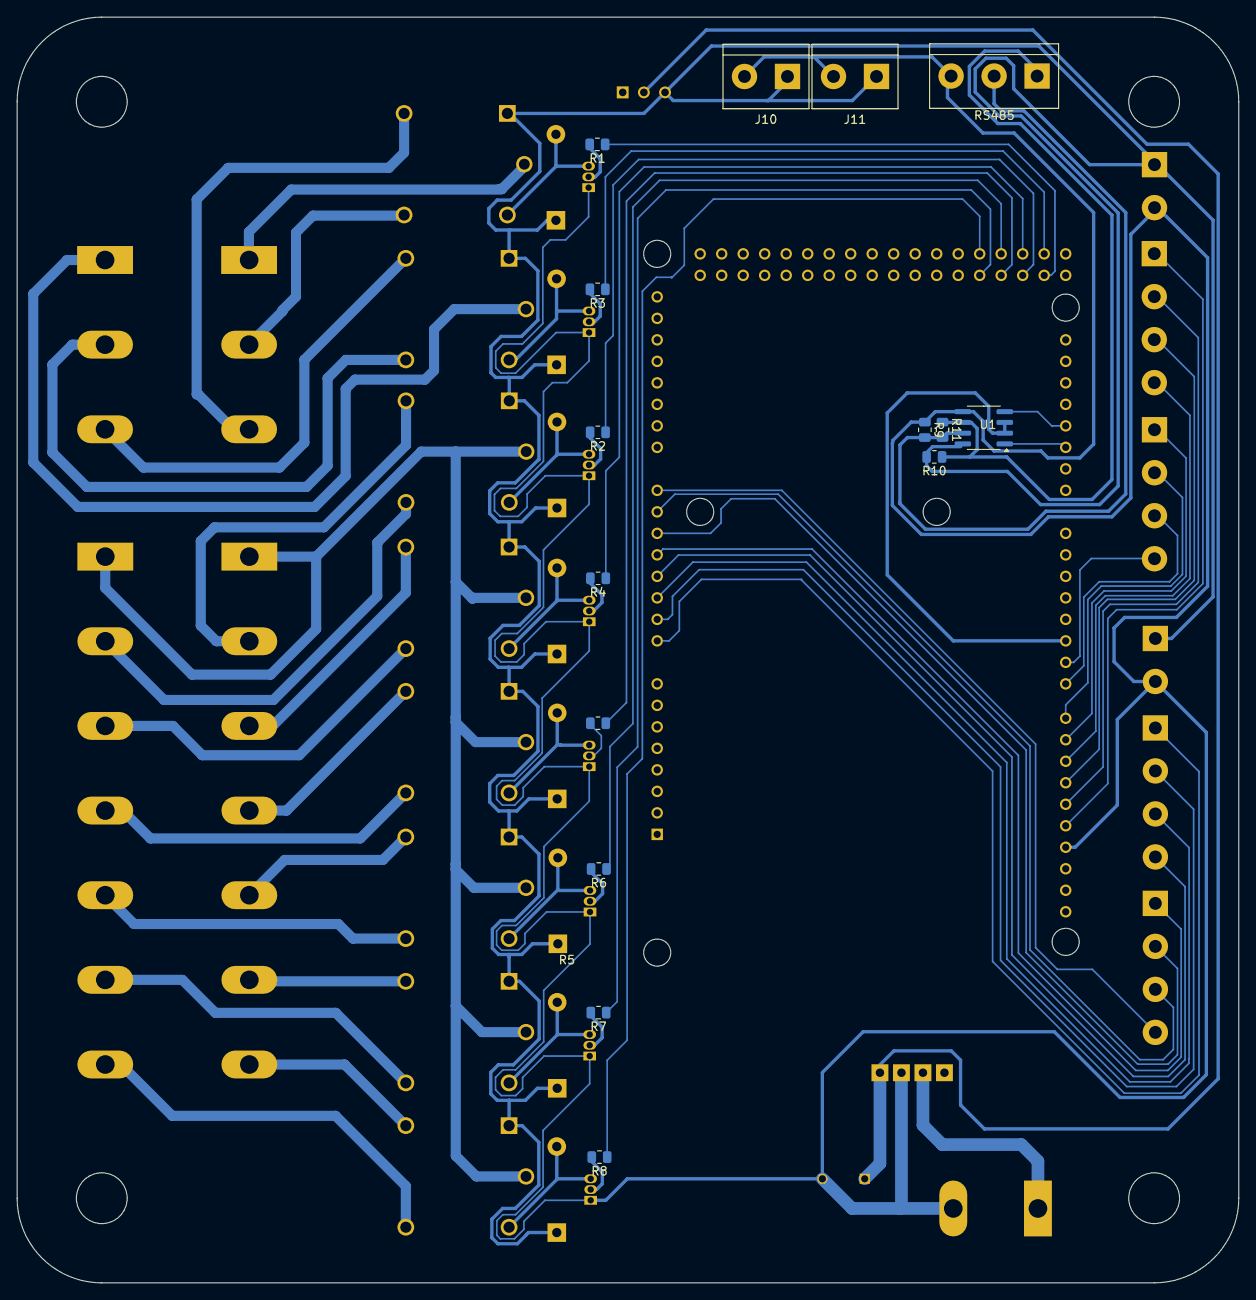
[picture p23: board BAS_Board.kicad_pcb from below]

Board: 2 copper layers, 144.3 x 149.5 mm, 54 parts (15 on the bottom side), 68 nets.

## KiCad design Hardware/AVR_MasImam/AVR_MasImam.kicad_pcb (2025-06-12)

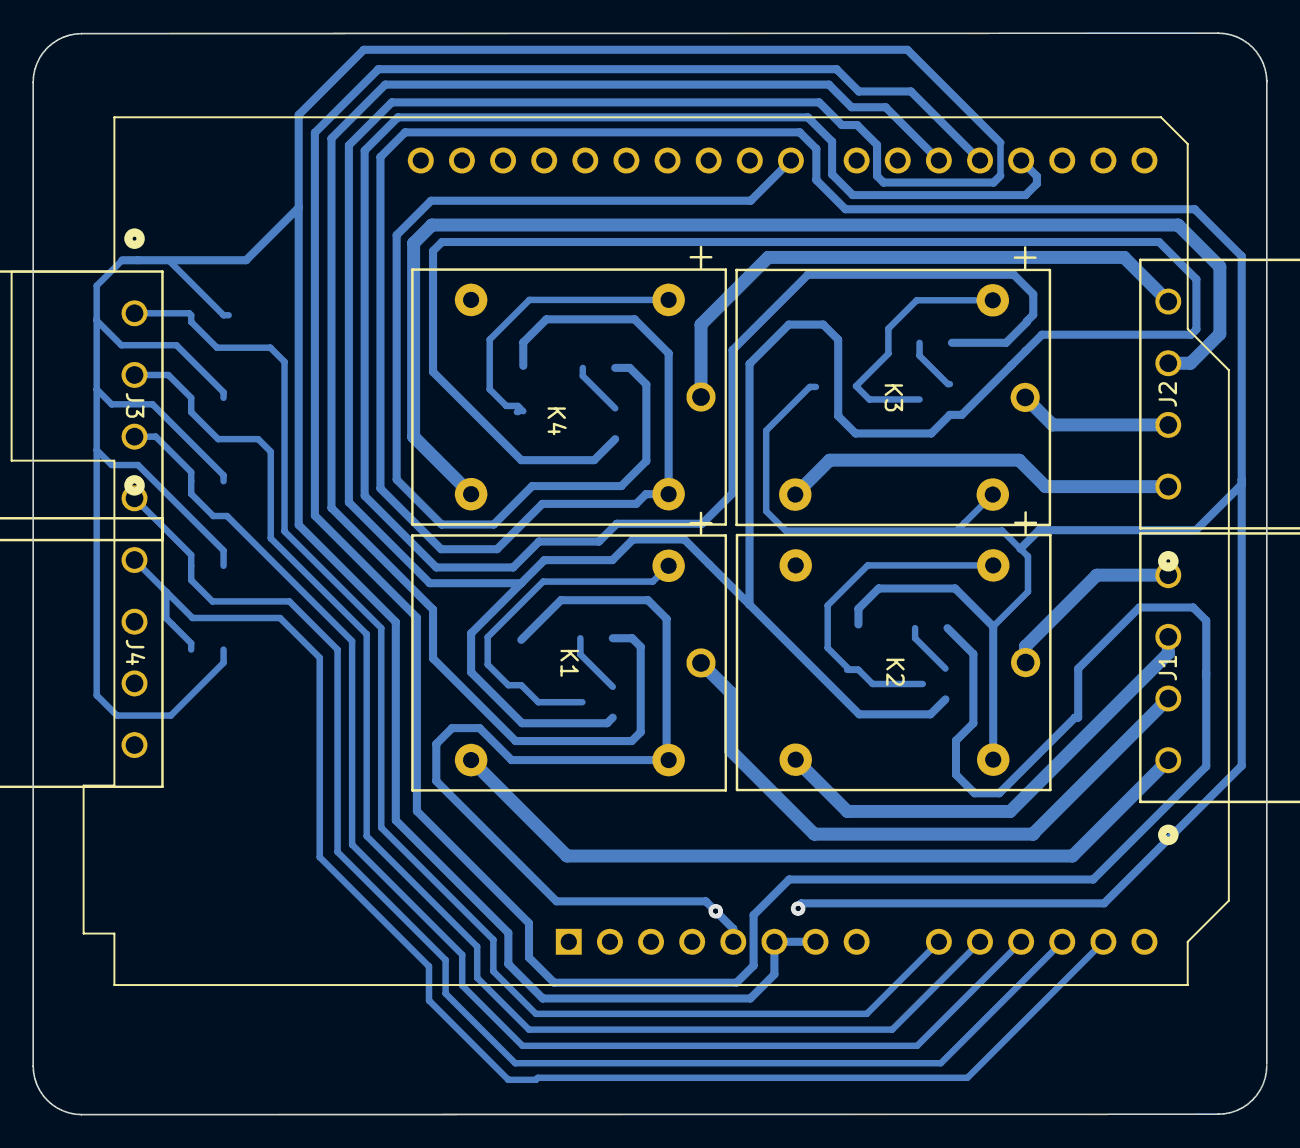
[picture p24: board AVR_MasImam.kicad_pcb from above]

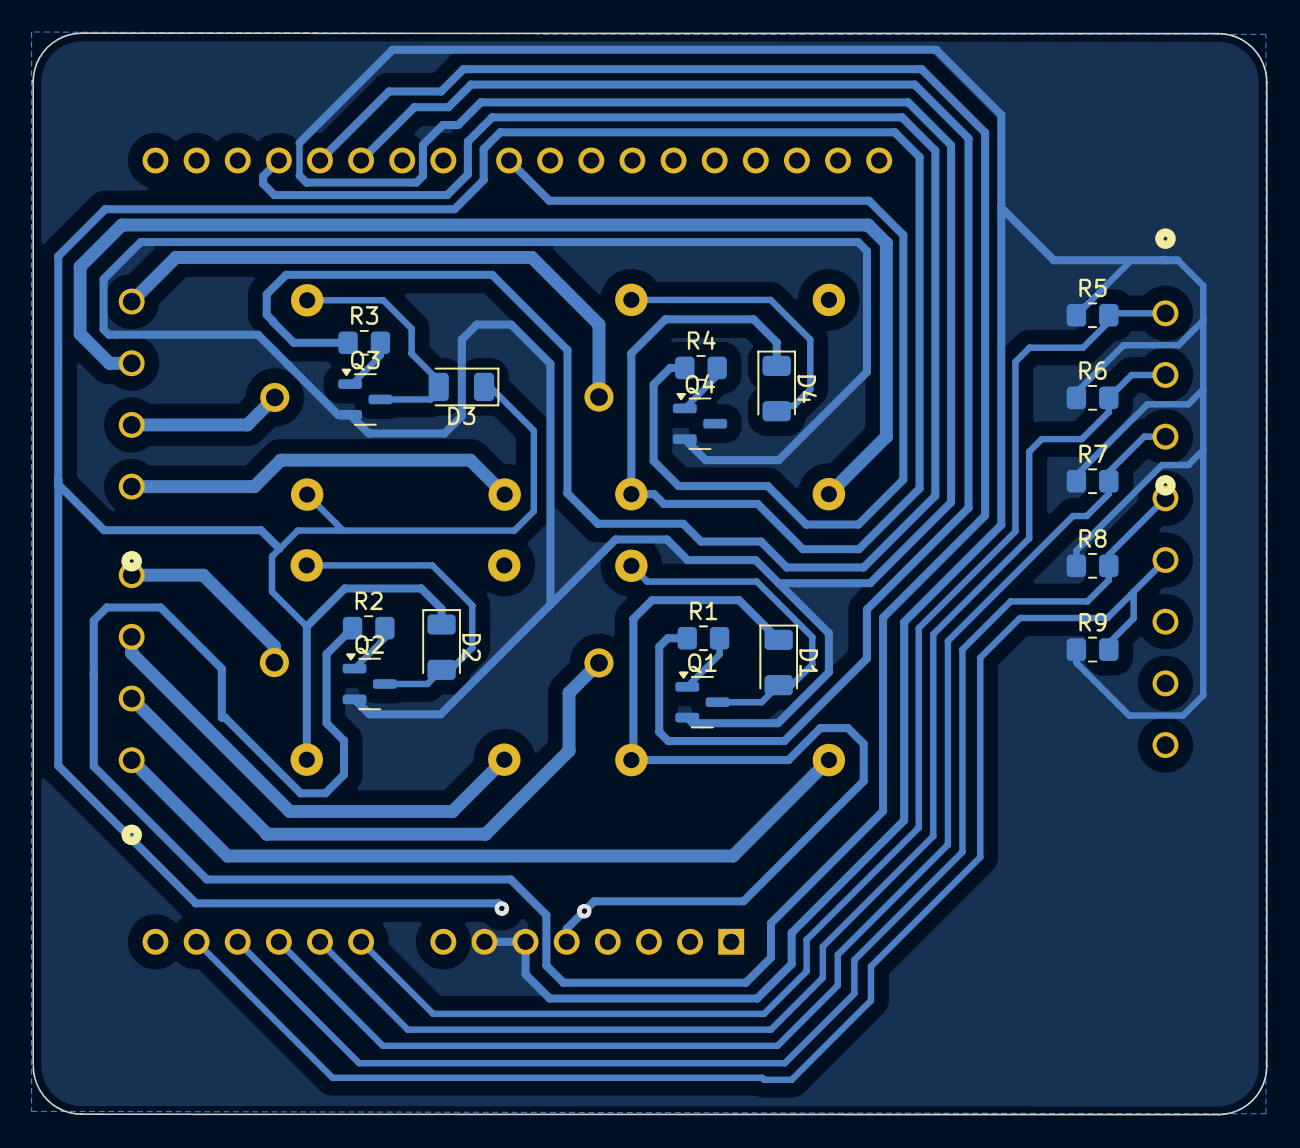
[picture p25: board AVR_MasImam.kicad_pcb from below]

Board: 2 copper layers, 76.2 x 66.8 mm, 26 parts (17 on the bottom side), 27 nets.

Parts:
A1: Arduino_UNO_R3
D1, D2, D3, D4: 1N4148; D_1206_3216Metric
J1, J2, J3, J4: WJ15EDGRC-3.81-4P; CONN_WJ15EDGRC-3.81-4P_KAN
K1, K2, K3, K4: SRD-05VDC-SL-C; RELAY_SRD-05VDC-SL-C_MCE
Q1, Q2, Q3, Q4: SS8050; SOT-23
R1, R2, R3, R4, R5, R6, R7, R8, R9: R10k; R_0805_2012Metric_Pad1.20x1.40mm_HandSolder

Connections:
5V: A1.5 (+5V), D1.1 (K), D2.1 (K), D3.1 (K), D4.1 (K), K1.5, K2.5, K3.5, K4.5
ADC0: A1.9 (A0), J3.1, R5.2
ADC1: A1.10 (A1), J3.2, R6.2
ADC2: A1.11 (A2), J3.3, R7.2
ADC3: A1.12 (A3), J3.4, R8.2
ADC4: A1.13 (SDA/A4), J4.1, R9.2
COM1: J1.2, K1.1
COM2: J1.4, K2.1
COM3: J2.2, K3.1
COM4: J2.4, K4.1
GND: A1.6 (GND), A1.7 (GND), Q1.2 (E), Q2.2 (E), Q3.2 (E), Q4.2 (E), R5.1, R6.1, R7.1, R8.1, R9.1
unnamed: D1.2 (A), K1.2, Q1.3 (C)
unnamed: D2.2 (A), K2.2, Q2.3 (C)
unnamed: D3.2 (A), K3.2, Q3.3 (C)
unnamed: D4.2 (A), K4.2, Q4.3 (C)
unnamed: Q1.1 (B), R1.2
unnamed: Q2.1 (B), R2.2
unnamed: Q3.1 (B), R3.2
unnamed: Q4.1 (B), R4.2
OUT1: A1.20 (D5), R1.1
OUT2: A1.19 (D4), R2.1
OUT3: A1.18 (D3), R3.1
OUT4: A1.23 (D8), R4.1
RNO1: J1.1, K1.4
RNO2: J1.3, K2.4
RNO3: J2.1, K3.4
RNO4: J2.3, K4.4

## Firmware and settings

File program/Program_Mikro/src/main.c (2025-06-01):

#include <avr/interrupt.h>
#include <avr/io.h>
#include <stdio.h>
#include <stdlib.h>
#include <string.h>
#include <util/delay.h>

#define BAUD 115200
#define USE_DOUBLE_SPEED 1

#if USE_DOUBLE_SPEED
#define UBRR_VALUE ((F_CPU / (8UL * BAUD)) - 1)
#else
#define UBRR_VALUE ((F_CPU / (16UL * BAUD)) - 1)
#endif

volatile uint8_t adc_enabled = 0;
volatile uint8_t do_enabled = 0;
volatile uint8_t di_enabled = 0;
volatile uint8_t adc_looping = 0;
volatile uint8_t di_looping = 0;
volatile uint8_t adc_loop = 0;
volatile uint8_t di_loop = 0;

volatile uint16_t adc_values[5] = {0};
volatile uint8_t adc_channel = 0;

volatile uint8_t output_state[4] = {0};
volatile uint8_t digital_inputs[3] = {0};

char rx_buffer[32];
volatile uint8_t rx_index = 0;
uint8_t adc_request_channel = 0xFF;
uint8_t di_request_channel = 0xFF;
uint8_t do_request_channel = 0xFF;
uint8_t do_request_state = 0;

// USART Functions
void USART_Init(void) {
#if USE_DOUBLE_SPEED
  UCSR0A |= (1 << U2X0);
#else
  UCSR0A &= ~(1 << U2X0);
#endif
  UBRR0H = (unsigned char)(UBRR_VALUE >> 8);
  UBRR0L = (unsigned char)UBRR_VALUE;
  UCSR0B = (1 << RXEN0) | (1 << TXEN0) | (1 << RXCIE0);
  UCSR0C = (1 << UCSZ01) | (1 << UCSZ00);
}

void USART_Transmit(unsigned char data) {
  while (!(UCSR0A & (1 << UDRE0)));
  UDR0 = data;
}

void USART_SendString(const char* str) {
  while (*str) {
    USART_Transmit(*str++);
  }
}

// ADC
void ADC_Init() {
  ADMUX = (1 << REFS0);
  ADCSRA = (1 << ADEN) | (1 << ADPS2);
}

uint16_t ADC_Read(uint8_t channel) {
  ADMUX = (1 << REFS0) | (channel & 0x07);
  ADCSRA |= (1 << ADSC);
  while (ADCSRA & (1 << ADSC));
  return ADC;
}

// Timer
void Timer1_Init_100ms() {
  TCCR1A = 0;
  TCCR1B = (1 << WGM12) | (1 << CS12);
  OCR1A = 6250 - 1;
  TIMSK1 = (1 << OCIE1A);
}

ISR(TIMER1_COMPA_vect) {
  if (adc_enabled && (adc_loop || adc_request_channel < 5)) {
    for (uint8_t ch = 0; ch < 5; ch++) {
      if (adc_loop || adc_request_channel == ch) {
        uint16_t val = ADC_Read(ch);
        char buf[32];
        snprintf(buf, sizeof(buf), "ADC%d=%u\r\n", ch, val);
        USART_SendString(buf);
      }
    }
    adc_request_channel = 0xFF;
  }

  if (di_enabled && (di_loop || di_request_channel < 3)) {
    digital_inputs[0] = (PINB >> 1) & 1;
    digital_inputs[1] = (PINB >> 2) & 1;
    digital_inputs[2] = (PINB >> 3) & 1;

    for (uint8_t i = 0; i < 3; i++) {
      if (di_loop || di_request_channel == i) {
        char buf[16];
        snprintf(buf, sizeof(buf), "IN%d=%d\r\n", i, digital_inputs[i]);
        USART_SendString(buf);
      }
    }
    di_request_channel = 0xFF;
  }

  if (do_enabled) {
    // Terapkan status output berdasarkan output_state[]
    if (output_state[0])
      PORTD |= (1 << PD5);
    else
      PORTD &= ~(1 << PD5);  // OUT1
    if (output_state[1])
      PORTD |= (1 << PD6);
    else
      PORTD &= ~(1 << PD6);  // OUT2
    if (output_state[2])
      PORTD |= (1 << PD7);
    else
      PORTD &= ~(1 << PD7);  // OUT3
    if (output_state[3])
      PORTB |= (1 << PB0);
    else
      PORTB &= ~(1 << PB0);  // OUT4
  }
}

ISR(USART_RX_vect) {
  char c = UDR0;
  if (c == '\n' || c == '\r') {
    rx_buffer[rx_index] = '\0';

    if (strcmp(rx_buffer, "ADC_Set") == 0)
      adc_enabled = 1;
    else if (strcmp(rx_buffer, "DI_Set") == 0)
      di_enabled = 1;
    else if (strcmp(rx_buffer, "DO_Set") == 0)
      do_enabled = 1;
    else if (strncmp(rx_buffer, "ADC", 3) == 0 && rx_buffer[4] == '\0')
      adc_request_channel = rx_buffer[3] - '0';
    else if (strncmp(rx_buffer, "IN", 2) == 0 && rx_buffer[3] == '\0')
      di_request_channel = rx_buffer[2] - '0';

    else if (strncmp(rx_buffer, "OUT", 3) == 0 && rx_buffer[5] == '\0') {
      uint8_t out_index = rx_buffer[3] - '1';  // OUT1 → index 0
      if (out_index < 4) {
        output_state[out_index] = rx_buffer[4] - '0';  // '1' = ON, '0' = OFF
      }
    }

    rx_index = 0;
  } else {
    if (rx_index < sizeof(rx_buffer) - 1) {
      rx_buffer[rx_index++] = c;
    }
  }
  if (strcmp(rx_buffer, "ADC_Loop") == 0) {
    adc_looping = 1;
    adc_enabled = 1;
  } else if (strcmp(rx_buffer, "DI_Loop") == 0) {
    di_looping = 1;
    di_enabled = 1;
  } else if (strcmp(rx_buffer, "ADC_Stop") == 0) {
    adc_looping = 0;
  } else if (strcmp(rx_buffer, "DI_Stop") == 0) {
    di_looping = 0;
  }
  if (strcmp(rx_buffer, "ADC_Loop") == 0)
    adc_loop = 1;
  else if (strcmp(rx_buffer, "ADC_Stop") == 0)
    adc_loop = 0;
  else if (strcmp(rx_buffer, "DI_Loop") == 0)
    di_loop = 1;
  else if (strcmp(rx_buffer, "DI_Stop") == 0)
    di_loop = 0;
}

int main(void) {
  USART_Init();
  ADC_Init();
  Timer1_Init_100ms();

  DDRC = 0x00;                                      // ADC input PC0-PC4
  DDRB |= (1 << PB0);                               // output PB0
  DDRB &= ~((1 << PB1) | (1 << PB2) | (1 << PB3));  // input PB1-3
  DDRD |= (1 << PD5) | (1 << PD6) | (1 << PD7);     // output PD5-7

  sei();

  while (1) {
  }
}

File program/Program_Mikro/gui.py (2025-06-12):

import tkinter as tk
from tkinter import PhotoImage, messagebox, ttk # Import ttk untuk styling
import os
import serial
import threading
import queue
import time
from collections import deque
from pathlib import Path

# Untuk grafik real-time
import matplotlib.pyplot as plt
from matplotlib.backends.backend_tkagg import FigureCanvasTkAgg
import matplotlib.animation as animation

# === CONFIG ===
SERIAL_PORT = 'COM23'  # <--- PASTIKAN INI SESUAI DENGAN PORT SERIAL MIKROKONTROLER ANDA
BAUD_RATE = 115200
THRESHOLD_ADC0 = 800   # Threshold untuk water level (raw ADC value)
THRESHOLD_ADC1 = 600   # Threshold untuk pressure (raw ADC value)

# Range konversi ADC ke nilai fisik
ADC_MAX_VALUE = 1023 # Untuk ADC 10-bit

# Water Level: 0-5 meter
WATER_LEVEL_MAX_METER = 5.0
WATER_LEVEL_ON_THRESHOLD_METER = 2.5 # Pompa nyala jika > 3 meter
WATER_LEVEL_OFF_THRESHOLD_METER = 0.5 # Pompa mati jika <= 0.5 meter

# Pressure: 0-10 Bar (asumsi standar untuk sensor pompa air)
PRESSURE_MAX_BAR = 10.0 
PRESSURE_MOTOR_OFF_THRESHOLD_BAR = 1.0 # Motor mati jika pressure <= 1.0 Bar

# Path untuk aset gambar
OUTPUT_PATH = Path(__file__).parent
ASSETS_PATH = OUTPUT_PATH / Path(r"C:\Users\ia088\Downloads\projek hendri\assets\frame0")

def relative_to_assets(path: str) -> Path:
    return ASSETS_PATH / Path(path)

# --- Queue untuk Komunikasi Antar Thread ---
# Data yang diterima dari serial akan dimasukkan ke queue ini oleh thread serial reader
# dan dibaca oleh main GUI thread.
serial_data_queue = queue.Queue()

# --- Fungsi Thread Pembaca Serial ---
def serial_reader_thread(ser_instance, data_queue):
    """
    Fungsi ini berjalan di thread terpisah untuk membaca data dari port serial.
    Data yang diterima akan dimasukkan ke dalam queue.
    """
    print(f"Serial reader thread started for {ser_instance.port}")
    while True:
        try:
            if ser_instance.is_open and ser_instance.in_waiting > 0:
                # Baca satu baris penuh yang diakhiri dengan newline/carriage return
                line = ser_instance.readline().decode('utf-8').strip()
                if line:
                    data_queue.put(line) # Masukkan data ke queue
                    # print(f"Received (thread): {line}") # Debugging
            time.sleep(0.01) # Beri sedikit delay agar tidak terlalu membebani CPU
        except serial.SerialException as e:
            print(f"Serial port error in thread: {e}")
            break # Keluar dari loop jika ada error serial
        except Exception as e:
            print(f"An unexpected error occurred in serial thread: {e}")
            break # Keluar dari loop jika ada error lain

class App:
    def __init__(self, master):
        self.master = master
        self.master.title("BAS Pump Monitoring System")
        self.master.geometry("1280x800")
        self.master.resizable(False, False)
        self.master.configure(bg="#FFFFFF")

        # Variabel status
        self.adc_values = {'ADC0': 0, 'ADC1': 0}
        self.monitoring = False
        self.out_states = {1: False, 2: False, 3: False} # OUT1: Pompa, OUT3: Lampu Motor
        self.mode = 0 # 0 for Manual, 1 for Auto
        self.state = 0 # 0 for OFF, 1 for ON (for pump)
        self.log = 0 # Bitmask for logging/grafik (0: None, 1: Log, 2: Grafik, 3: Keduanya)

        # Inisialisasi Serial Port
        self.ser = None
        
        try:
            self.ser = serial.Serial(SERIAL_PORT, BAUD_RATE, timeout=0.1)
            time.sleep(2) # Tunggu sebentar agar Arduino siap
            print(f"Koneksi serial ke {self.ser.port} berhasil dibuka.")
            
            # Mulai thread pembaca serial
            self.serial_thread = threading.Thread(target=serial_reader_thread, args=(self.ser, serial_data_queue), daemon=True)
            self.serial_thread.start()

            # Kirim perintah awal ke mikrokontroler
            self.send_command_to_mcu("DO_Set") # Aktifkan Digital Output
            self.send_command_to_mcu("ADC_Set") # Aktifkan ADC secara global
            self.send_command_to_mcu("ADC_Loop") # Mulai ADC Loop untuk semua channel
            print("Initial commands (DO_Set, ADC_Set, ADC_Loop) sent.")

            self.send_command_to_mcu(f"OUT1{1}")
            
        except serial.SerialException as e:
            messagebox.showerror("Serial Port Error", f"Tidak dapat membuka port serial {SERIAL_PORT}:\n{e}\nPastikan mikrokontroler terhubung dan port yang benar dipilih.")
            print(f"Error: Tidak dapat membuka port serial {SERIAL_PORT} - {e}")
            self.master.destroy() # Tutup jendela jika gagal membuka serial port
            return

        # === GUI Elements ===
        self.canvas = tk.Canvas(
            self.master,
            bg="#FFFFFF",
            height=800,
            width=1280,
            bd=0,
            highlightthickness=0,
            relief="ridge"
        )
        self.canvas.place(x=0, y=0)
        
        # Muat semua gambar
        self.load_images()
        self.place_images()
        
        # --- Konfigurasi Style untuk Progress Bar ---
        self.style = ttk.Style()
        
        # Gaya baru untuk Progress Bar (Baby Blue)
        # Warna biru muda yang mendekati gambar
        baby_blue_fill = "#87CEEB" # Sky Blue
        baby_blue_trough = "#E0F2F7" # Light Cyan (untuk area tidak terisi)
        # Untuk border/efek 3D, kita bisa gunakan warna yang sedikit lebih gelap atau terang
        baby_blue_border = "#6495ED" # Cornflower Blue (untuk border/efek 3D)

        # Konfigurasi elemen 'bar' dan 'trough' dari progressbar
        # `troughcolor`: Warna background (area tidak terisi)
        # `background`: Warna bar terisi
        # `bordercolor`, `lightcolor`, `darkcolor`: Untuk efek 3D border
        # `relief`: Tipe relief (flat, sunken, raised, groove, ridge)
        # `borderradius`: Untuk sudut membulat (tidak didukung secara langsung oleh semua tema ttk)
        
        # Kita akan membuat style baru yang spesifik untuk progress bar kita
        self.style.element_create("progressbar.trough", "from", "clam")
        self.style.element_create("progressbar.pbar", "from", "clam")
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

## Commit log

2025-05-25 add hardware
    [AVR_MasImam.kicad_pcb, AVR_MasImam.kicad_sch]
2025-06-02 Create Desain PCB
